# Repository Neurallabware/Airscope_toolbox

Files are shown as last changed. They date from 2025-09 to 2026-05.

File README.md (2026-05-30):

<p align="center">
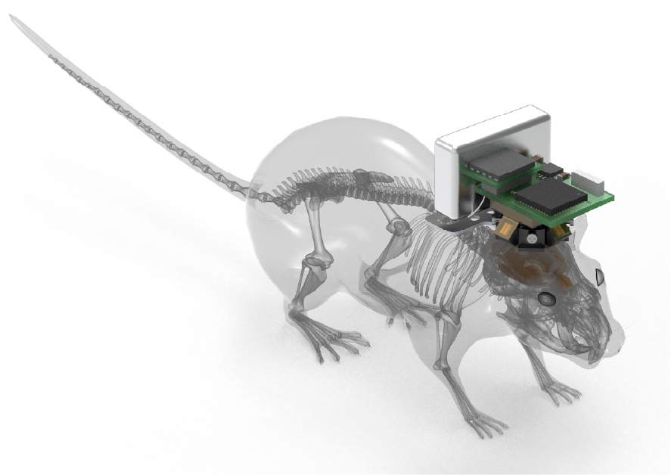
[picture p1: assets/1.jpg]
Airscope
  
</p>

<h1 align="center">Airscope</h1>

<p align="center">
  <b>A 1-gram wireless mesoscope for cortex-wide, single-cell-resolution imaging during unrestricted behaviour</b>
</p>

<p align="center">
  <a href="https://airscope.org/devkit/">Device Docs</a> ·
  <a href="https://airscope-docxs.readthedocs.io/en/latest/">Software Docs</a> ·
  <a href="https://drive.google.com/drive/folders/1z9ibX8Ob2NnCdjQDHI7Z4tdhdspn647B?usp=drive_link">Data Release</a>
</p>

---

Airscope is an open hardware and software platform for wireless mesoscopic calcium imaging in freely behaving mice. The device achieves a **6 mm field of view** at ~4 µm lateral resolution, streams or logs **1600 × 1200 px images at 10 Hz**, and weighs approximately **1 g**.

<p align="center">
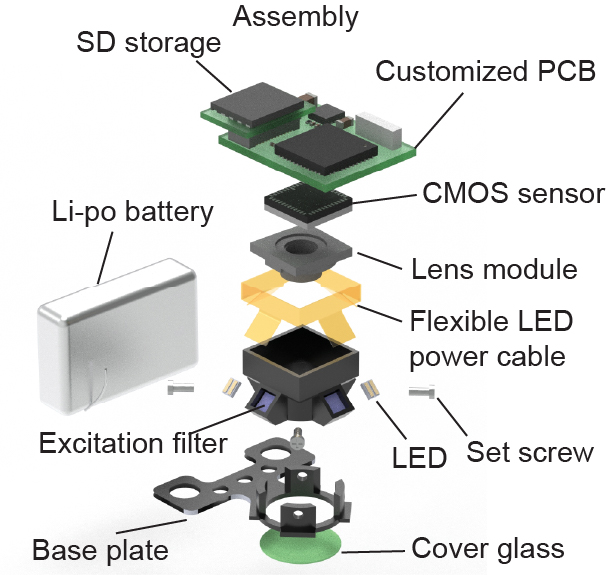
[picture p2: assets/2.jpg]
Airscope examples
  
</p>

This repository accompanies the manuscript:

> **Deciphering cortex-wide neural dynamics of naturally behaving mice by a 1-gram wireless mesoscope**
> *Zhang et al., Nature, 2025* （Manuscript in preparation）

---

## Repository Structure

| Directory | Description |
|---|---|
| [`Structure/`](./Structure) | SolidWorks assemblies and part files — housing, baseplate, optical mount, PCB carrier, flexible LED board |
| [`Zemax/`](./Zemax) | Zemax optical design files for the aspheric module |
| [`Electronics/`](./Electronics) | KiCad projects for the main PCB and auxiliary boards |
| [`Firmware/`](./Firmware) | Embedded code for wireless control, camera acquisition, and device configuration |
| [`DAQ_software/`](./DAQ_software) | Python host software and Windows installer for device discovery, preview, and recording |
| [`Software/`](./Software) | Calcium-imaging processing, behavioural segmentation, and neural-decoding pipelines |
| [`Data_release/`](./Data_release) | Example datasets, visualization notebooks, and download instructions |

---

## Key Capabilities

- **Cortex-wide cellular imaging** — 6 mm FOV with single-cell spatial resolution across the dorsal cortex
- **Untethered operation** — wireless data transfer and on-board logging for freely moving, multi-animal, and aquatic paradigms
- **Integrated acquisition stack** — firmware + host software for discovery, preview, timestamping, and recording
- **Reproducible calcium processing** — motion correction → background removal → neuron segmentation → trace extraction
- **Behavioural analysis** — SAM2Mice for multi-animal tracking; Neuron-BERT for decoding social-interaction outcomes

---

## Software Modules

### Calcium-imaging processing · [`Software/Airscope_ca_processing`](./Software/Airscope_ca_processing)

End-to-end pipeline from raw frames to segmented ROI traces. Accepts image sequences, TIFF stacks, and MP4 input; configured with [Hydra](https://hydra.cc) for reproducible batch runs.

```bash
cd Software/Airscope_ca_processing
conda create -n PICO python=3.10 && conda activate PICO
pip install -r requirements.txt && pip install -e .
```

```bash
airscope-process \
  data_path=/path/to/session/frames \
  out_path=/path/to/session/analysis \
  rmbg.gpu_ids=0 rmbg.multi_gpu=false
```

Primary outputs: `seg_results_filtered.mat`, `infer_results_filtered.mat`, `cm_filtered.mat`

---

### SAM2Mice · [`Software/SAM2Mice`](./Software/SAM2Mice)

SAM 2–based mouse segmentation and tracking. Supports manual prompts, YOLOv11 auto-prompts, and bootstrapped inference for videos that exceed GPU memory.

```bash
cd Software/SAM2Mice
pip install torch==2.6.0 torchvision==0.21.0 torchaudio==2.6.0 --index-url https://download.pytorch.org/whl/cu124
pip install -e ".[notebooks]" && python setup.py build_ext --inplace
```

Notebooks in [`Software/SAM2Mice/notebooks_SAM2-MICE`](./Software/SAM2Mice/notebooks_SAM2-MICE) cover basic segmentation, long-video bootstrapping, automatic tracking, and public-dataset examples.

---

### Neuron-BERT · [`Software/Neuron_BERT`](./Software/Neuron_BERT)

Transformer-based decoder for predicting social-interaction outcomes from dual-animal neural activity recordings.

---

### Host acquisition software · [`DAQ_software/`](./DAQ_software)

Dependency-free Python backend — runs without any additional packages:

```bash
cd DAQ_software/airscope_pybackend
python server.py
# UI available at http://127.0.0.1:8765/
```

A packaged Windows installer is also provided at [`DAQ_software/airscope.msi`](./DAQ_software/airscope.msi).

---

## Data Release

Example datasets are hosted on [Google Drive](https://drive.google.com/drive/folders/1z9ibX8Ob2NnCdjQDHI7Z4tdhdspn647B?usp=drive_link) and documented in [`Data_release/README.md`](./Data_release/README.md).
The Google Drive root README is maintained at [`Data_release/README_google_drive.md`](./Data_release/README_google_drive.md) and can be uploaded to Drive as `README_google_drive.md`.

| Dataset | Contents |
|---|---|
| Enriched habitat | Calcium traces, multi-view behaviour videos, detection boxes, arena annotations, cortical labels, neuron centroids |
| Multi-animal interaction | Calcium traces, SAM2 instance masks, mouse trajectories, cortical labels, neuron centres |
| MCU timestamp | Frame-rate validation files; use `calculate_frame_rate.ipynb` to verify |
| Optical characterisation | USAF 1951 target images and fluorescent grid slides |

Each dataset directory includes a `README.md` and a `visualize_data.ipynb` notebook.

---

## Requirements

| Component | Environment |
|---|---|
| Host acquisition software | Python ≥ 3.9, standard library only |
| Calcium processing | Linux, Python 3.10, CUDA-enabled PyTorch recommended |
| SAM2Mice | Python 3.11, PyTorch 2.6.0, CUDA 12.4 |
| Neuron-BERT | Python 3.x, PyTorch, NumPy, scikit-learn, pandas, matplotlib |

See the component-level `README.md` files for exact commands and configuration.

---

## Licensing

Airscope is distributed as a multi-licence repository:

| Material | Licence |
|---|---|
| Hardware design (`Structure/`, `Electronics/`, `Zemax/`) | CERN-OHL-S-2.0 |
| Software (`DAQ_software/`, `Firmware/`, `Software/`) | GPL-3.0-only |
| Documentation, figures, notebooks, released data | CC-BY-4.0 |

See [`LICENSE`](./LICENSE), [`LICENSES/`](./LICENSES), and [`NOTICE.md`](./NOTICE.md) for the authoritative licence map and third-party notices.

---

## Citation

```bibtex
@article{airscope2025,
  title   = {Deciphering cortex-wide neural dynamics of naturally
             behaving mice by a 1-gram wireless mesoscope},
  author  = {Zhang, Yuanlong and Li, Angran and Yuan, Lekang and
             Wang, Mingrui and Zhao, Weihao and Wang, Zhenbo and
             Zang, Boyang and Zhou, Yangxuan and Yu, Tao and Gao, Lin
             and Wu, Yu and Zhu, Rongkang and Tian, Mengyi and Li, Kun
             and Wu, Jiamin and Dai, Pu and Dai, Qionghai},
  journal = {Nature},
  year    = {2025},
  note    = {Manuscript in preparation}
}
```

## Documentation

- Device assembly, acquisition, and operation: <https://airscope.org/devkit/>
- Processing pipelines, notebooks, and examples: <https://airscope-docxs.readthedocs.io/en/latest/>

## Contact

Questions, bug reports, and suggestions can be submitted via the issue tracker or sent to the corresponding authors listed in the manuscript.

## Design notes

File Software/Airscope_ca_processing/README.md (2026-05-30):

# Airscope calcium imaging processing

Official processing code for Deciphering cortex-wide neural dynamics of naturally behaving mice by 1-gram wireless mesoscope.

<p align="center">
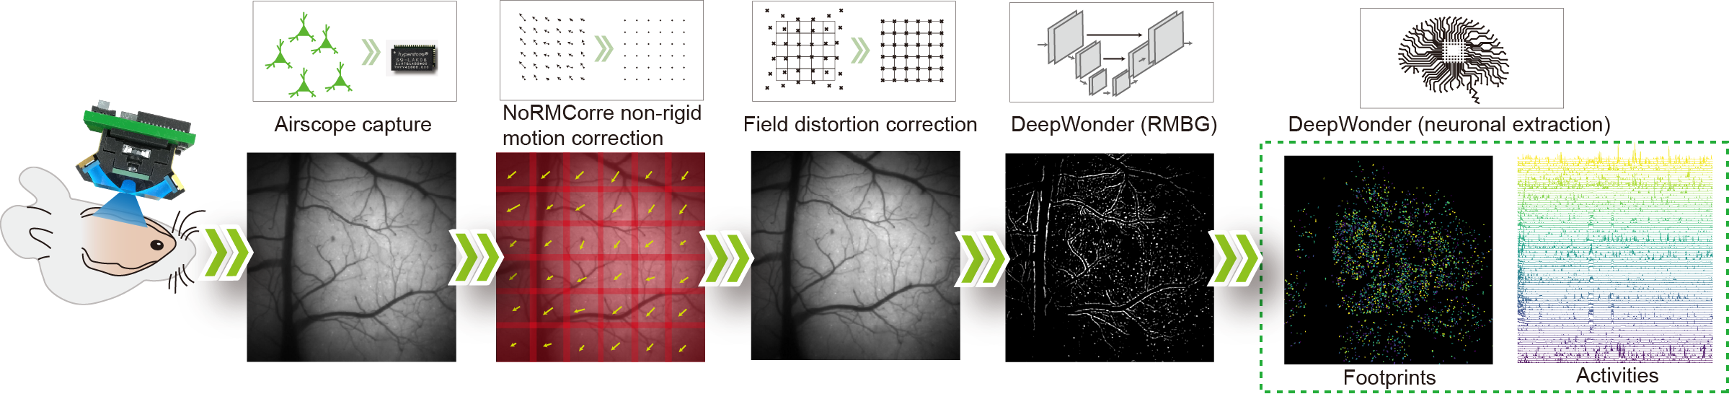
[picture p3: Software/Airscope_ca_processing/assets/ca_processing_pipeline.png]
  
</p>
Airscope_ca_processing processes sequential imaging frames through motion correction,preprocessing, background removal, neuron segmentation, and trace export.

- End-to-end processing pipeline for cortex-wide PICO calcium imaging.
- Suite2p-style or CaImAn-style motion correction configs.
- Learned background removal and vessel-aware filtering.
- Hydra-based configuration for reproducible batch processing.
- Exported masks and traces for downstream analysis.

## Installation

The tested environment is Linux with Python 3.10 and CUDA 11.8.

```bash
conda create -n PICO python=3.10
conda activate PICO
pip install -r requirements.txt
pip install -e .
```

Check the installation:

```bash
python - <<'PY'
import torch
import Airscope_ca
print("Airscope_ca import OK")
print("torch:", torch.__version__, "cuda:", torch.version.cuda)
print("cuda available:", torch.cuda.is_available())
PY
```

## Checkpoints

Download the checkpoint files from:

[[`Google Drive`](https://drive.google.com/drive/folders/1UuLxzTA0PmYvqz8UPbQ9a1BIXx_mHZjt?dmr=1&ec=wgc-drive-%5Bmodule%5D-goto)]

Place the downloaded files under the repository-level `ckpt/` directory:

```text
ckpt/
  CorrectionMap.npz
  background_rejection_ckpt_resize_2
  vessel_model.pt
  yolo_v8s.pt
```

The default configs expect these paths. If you store the files elsewhere, update the corresponding config values under `configs/`.

## Input Format

The pipeline supports `jpg`, `tif`, and `mp4` inputs through `data_format`.
For image sequences, use grayscale frames named by frame index:

```text
data/session/frames/
  frame_0.jpg
  frame_1.jpg
  frame_2.jpg
  ...
```

For TIFF input, use the same naming pattern with `.tif`. For MP4 input, set
`data_path` to the MP4 file path, or to a directory containing exactly one
`.mp4` file. The number of frames is inferred from `data_format` unless
`set_frame_num` is provided.

## Running

Run the full pipeline:

```bash
airscope-process \
  data_path=/path/to/session/frames \
  out_path=/path/to/session/analysis \
  rmbg.gpu_ids=0 \
  rmbg.multi_gpu=false
```

For a short smoke test:

```bash
airscope-process \
  data_path=/path/to/session/frames \
  out_path=/tmp/pico_smoke_test \
  set_frame_num=100 \
  rmbg.gpu_ids=0 \
  rmbg.multi_gpu=false \
  save_debug_video=false
```

Common overrides:

| Override | Description |
| --- | --- |
| `data_path` | Input frame directory for `jpg`/`tif`, or MP4 path for `mp4` |
| `data_format=jpg/tif/mp4` | Select input format |
| `out_path` | Output directory |
| `set_frame_num` | Limit the number of processed frames; `0` infers all frames |
| `motion=caiman` / `motion=suite2p` | Select motion correction config |
| `rmbg.gpu_ids=0,1` | Select GPUs for background removal |
| `rmbg.multi_gpu=true` | Enable multi-GPU background removal |
| `jump_to_rmbg=true` | Reuse existing motion/preprocessing outputs |
| `jump_to_seg=true` | Reuse existing background-removed output |
| `save_debug_video=false` | Disable debug AVI export |

Typical outputs include:

```text
Analysis/
├── log_file.log
├── badframe_replaced.avi                    # optional raw-frame QC video
├── mc/
│   ├── motion_corrected.zarr                # motion-corrected calcium movie
│   ├── suite2p_shifts.png                   # rigid x/y shift diagnostic
│   ├── suite2p_refImg.png                   # registration reference image
│   └── suite2p_refImg.npy                   # numeric reference image
├── preprocess/
│   └── video_preprocessed.zarr              # distortion/intensity corrected movie
├── rmbg/
│   └── rmbg.zarr                            # neuron-enhanced movie after background removal
├── vessel_image.tif                         # vessel-channel image used for exclusion
├── vessel_mask.tif                          # raw vessel mask
├── vessel_mask.png                          # vessel-mask QC figure
├── vessel_mask_clean.tif                    # small-component cleaned vessel mask
├── vessel_mask_dilate.tif                   # dilated vessel mask used for ROI filtering
└── seg_results_thresh_pmap_<value>/
    ├── patch_<row>_<col>/                   # patch-level segmentation workspace
    ├── seg_results.mat                      # unfiltered ROI masks
    ├── infer_results.mat                    # unfiltered calcium traces
    ├── cm.mat                               # unfiltered ROI center coordinates
    ├── SEG_SUM.png                          # unfiltered summed ROI mask
    ├── cm.png / cm.svg                      # unfiltered ROI-center plot
    ├── seg_results_filtered.mat             # vessel/shape filtered ROI masks
    ├── infer_results_filtered.mat           # filtered calcium traces
    ├── cm_filtered.mat                      # filtered ROI center coordinates
    ├── SEG_SUM_filtered.png                 # filtered summed ROI mask
    ├── cm_wo_vessel.png / cm_wo_vessel.svg  # filtered ROI-center plot
    ├── neuron_mask.png / neuron_mask.svg    # filtering summary overlay
    └── Neuron_trace/
        ├── whole_neurons.png
        └── <start>_to_<end>.png             # trace panels by ROI block
```

The final files used for downstream calcium analysis are usually
`seg_results_filtered.mat`, `infer_results_filtered.mat`, and `cm_filtered.mat`.

## Notebooks

Interactive QC notebooks are provided for each processing stage (motion correction, preprocessing, background removal, segmentation, and export). See [`notebooks/README.md`](notebooks/README.md) for demo data download, path setup, and the full stage map.

## Configuration

Configs are stored in `configs/`. The top-level config is:

```text
configs/config.yaml
```

Default groups:

```text
configs/motion/
configs/preprocessing/
configs/rmbg/
configs/segmentation/
```

Hydra overrides can be passed directly on the command line.

## Citation

If this code is useful for your work, please cite:

```text
Yuanlong Zhang, Angran Li, Lekang Yuan, Mingrui Wang.
Deciphering cortex-wide neural dynamics of naturally behaving mice by 1-gram wireless mesoscope.
```

See `CITATION.cff` for machine-readable citation metadata.

## License

This repository is released under the GNU General Public License v3.0 only. See `LICENSE`.

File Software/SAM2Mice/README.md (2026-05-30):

# SAM2Mice: Zero-Shot Multi-Animal Semantic Segmentation

[[`SAM 2 Paper`](https://arxiv.org/abs/2408.00714)] [[`YOLO v11 Paper`](https://www.arxiv.org/abs/2410.17725)] [[`BibTeX`](#citation)]

**SAM2Mice** extends the SAM 2 video segmentation framework for multi-animal mouse segmentation and tracking. It combines SAM2Mice checkpoints, YOLOv11 prompt generation, manual SAM2 prompt workflows, and bootstrapped long-video inference.

Highlights:

- Curated multi-mouse segmentation data with diverse camera views and environments.
- Bootstrapping inference for long videos that cannot be loaded into GPU memory at once.
- Benchmarking support against DeepLabCut and SuperAnimal using MOT metrics.

<p align="center">
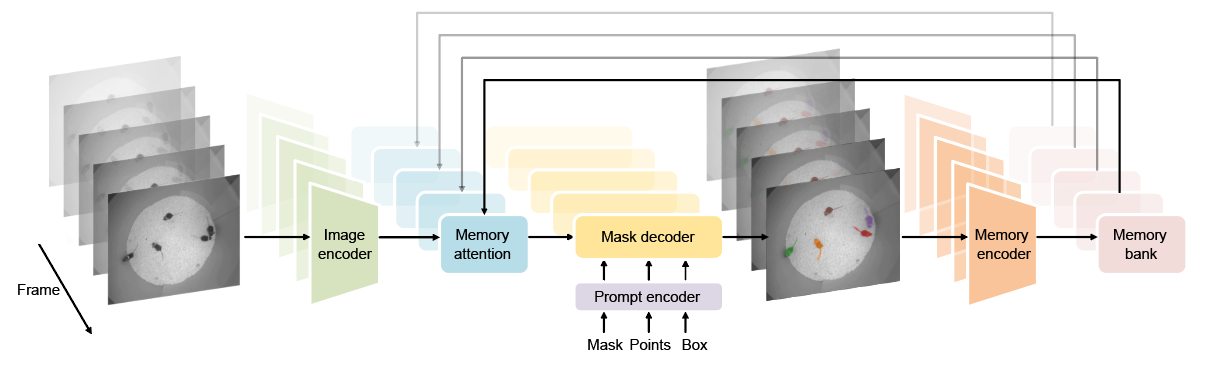
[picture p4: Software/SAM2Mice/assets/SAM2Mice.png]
SAM2Mice
  
</p>

<p align="center">
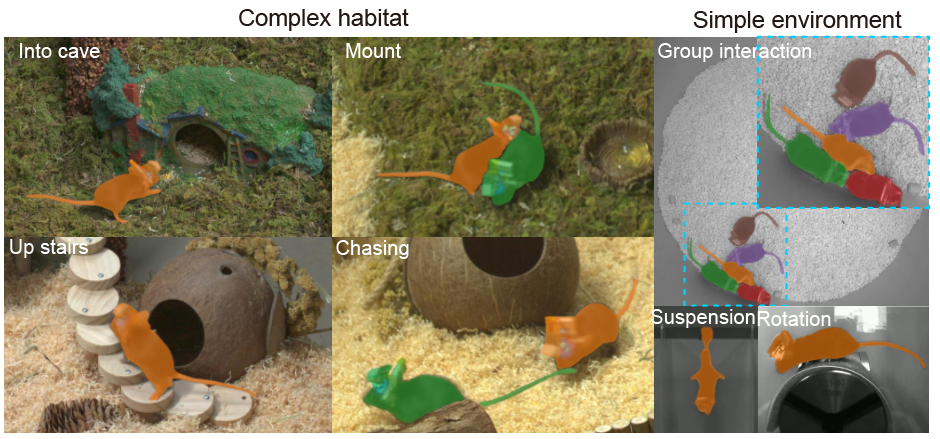
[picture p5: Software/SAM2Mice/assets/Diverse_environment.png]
Diverse environments
  
</p>

## Quick Start

Create or activate a Python environment first. We use `python=3.11`, `torch>=2.6.0`, `torchvision>=0.21.0`, and CUDA 12.4 in our demo environment.

```bash
pip install torch==2.6.0 torchvision==0.21.0 torchaudio==2.6.0 --index-url https://download.pytorch.org/whl/cu124
pip install -e ".[notebooks]"
python setup.py build_ext --inplace
```

Download the SAM2Mice checkpoint:

```bash
cd checkpoints
bash download_ckpts.sh
cd ..
```

Download the YOLOv11 detector checkpoint:

```bash
cd checkpoints_detection
bash download_ckpts.sh
cd ..
```

The YOLO checkpoint is intended for top-down open-field videos. You can also download the SAM2Mice checkpoint directly from [Google Drive](https://drive.google.com/file/d/1aTYiL1qt23vUAGbHvh2Yrk3r16i95bnU/view?usp=drive_link).

## Notebooks

Run the notebooks in order if you are new to the project:

| Order | Notebook | Purpose |
| --- | --- | --- |
| 1 | [`01_basic_video_segmentation.ipynb`](./notebooks_SAM2-MICE/01_basic_video_segmentation.ipynb) | Manual prompts and YOLO-generated prompts on one video. |
| 2 | [`02_bootstrapping_long_video.ipynb`](./notebooks_SAM2-MICE/02_bootstrapping_long_video.ipynb) | Long-video segmentation with bootstrapped frame batches. |
| 3 | [`03_auto_tracking_dynamic_ids.ipynb`](./notebooks_SAM2-MICE/03_auto_tracking_dynamic_ids.ipynb) | Automatic tracking with dynamic IDs. |
| 4 | [`04_public_datasets_demo.ipynb`](./notebooks_SAM2-MICE/04_public_datasets_demo.ipynb) | Public mouse behavior dataset examples. |
| 5 | [`05_vos_inference_advanced.ipynb`](./notebooks_SAM2-MICE/05_vos_inference_advanced.ipynb) | Advanced VOS inference utilities. |

Demo data can be downloaded from [Google Drive](https://drive.google.com/drive/folders/1h3JZ6n-LhZRwAsLCKLH60XWioy7f3WPZ). See [`docs/google_drive_data.md`](./docs/google_drive_data.md) for the full folder structure and per-file Drive IDs.

## Manual Prompts

Manual SAM2 prompts are saved as LabelMe-compatible `.json` files next to extracted frames. SAM2Mice supports two prompt creation tools:

- **LabelMe desktop GUI**: use this when you have a local graphical desktop or X11 forwarding.
- **SAM2-Mice browser prompt tool**: use `launch_annotator` on a remote server or headless workstation.

See the standalone manual prompt guide: [`docs/prompts/README.md`](./docs/prompts/README.md).

## Inference Workflows

SAM2Mice supports two prompt sources:

- `manual`: read LabelMe-style `.json` prompt files from the frame directory.
- `detection`: use YOLOv11 to generate prompts automatically.

When using `prompt_source="detection"`, the supported `prompt_type` values are `box`, `point`, and `mask`.

Results are automatically saved as a gzip-compressed pickle (`segment_masks.pickle`) in `save_dir`. See [`docs/results_pkl.md`](./docs/results_pkl.md) for save/load and re-rendering details.

### Basic Video Segmentation

<details>
<summary><b>Manual prompts (point)</b></summary>

Extract frames and launch the browser-based GUI annotator to place point prompts on the first frame, then run segmentation:

```python
from SAM2_Mice.segmentation import VideoSegmentationInference
from SAM2_Mice.utils import launch_annotator

model_cfg = "configs/sam2.1/sam2.1_hiera_b+.yaml"
checkpoint_path = "checkpoints/SAM2_Mice_base_plus.pt"
video_path = "data/test_video.mp4"
frames_dir = "data/frames"

predictor = VideoSegmentationInference(
    model_cfg=model_cfg,
    checkpoint_path=checkpoint_path,
)

predictor.extract_frames_before_seg(
    video_path=video_path,
    frame_dir=frames_dir,
)

# Launch GUI to annotate the first frame; saves a LabelMe-compatible .json prompt file
launch_annotator(frames_dir=frames_dir)

predictor.run(
    video_path=None,
    frames_dir=frames_dir,
    prompt_source="manual",
    prompt_type="point",
    save_dir="results/base",
    fps=20,
)
```

</details>

### Bootstrapping Long Videos

Processing high-resolution long videos with the standard SAM 2 video predictor can be GPU-intensive because all frames are loaded into memory. SAM2Mice bootstrapping splits the video into overlapping frame batches and carries prompts forward through the shared boundary frame.

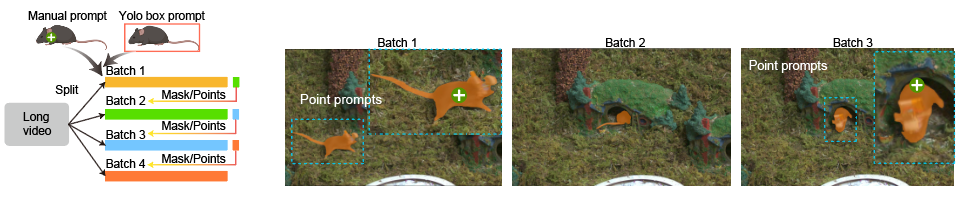
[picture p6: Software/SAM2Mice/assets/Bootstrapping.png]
Bootstrapping


<details>
<summary><b>Manual prompts (point)</b></summary>

Extract batched frames, annotate the first frame with the GUI, then run bootstrapped segmentation:

```python
from SAM2_Mice.segmentation import BootstrappingVideoSegmentationInference
from SAM2_Mice.utils import launch_annotator

model_cfg = "configs/sam2.1/sam2.1_hiera_b+.yaml"
checkpoint_path = "checkpoints/SAM2_Mice_base_plus.pt"
video_path = "data/test_video.mp4"
frames_dir = "data/bootstrap_frames"
batch_size = 300

predictor = BootstrappingVideoSegmentationInference(
    model_cfg=model_cfg,
    checkpoint_path=checkpoint_path,
)

predictor.extract_bootstrapping_frames(
    video_path=video_path,
    batch_size=batch_size,
    batch_save_dir=frames_dir,
)

# Launch GUI to annotate the first frame of the first batch
launch_annotator(frames_dir=frames_dir)

predictor.run_bootstrapping(
    video_path=None,
    frames_dir=frames_dir,
    frame_interval=batch_size,
    extract_frame=False,
    prompt_source="manual",
    prompt_type="point",
    detection_frame_idx=0,
    detection_ckpt_path="checkpoints_detection/yolo11l_openfield_five_mice.pt",
    save_dir="results/bootstrapping",
    fps=20,
)
```

</details>

### YOLO Prompt Generation

YOLOv11 can generate the first-frame prompts automatically:

- `box`: use detector boxes directly.
- `point`: sample points from SAM2 masks predicted from detector boxes.
- `mask`: use SAM2 masks predicted from detector boxes.

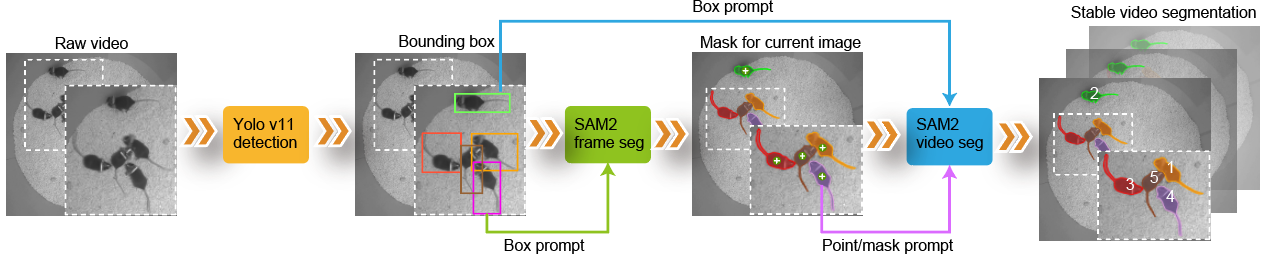
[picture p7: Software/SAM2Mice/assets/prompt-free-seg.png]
Prompt-free segmentation


> **Note:** The YOLO detector is trained on SAM2Mice masks from a specific recording setup (top-down open-field view). It works best when the new video matches that setup closely. For new environments or camera angles, re-train a YOLO detector on SAM2-generated masks from a short representative clip of the new recording — see [`training/README.md`](./training/README.md).

Set `prompt_source="detection"` in either the basic or bootstrapping workflow to use this mode.

<details>
<summary><b>YOLO automatic prompts (point)</b></summary>

Use YOLOv11 to generate point prompts automatically from the first frame — no manual annotation needed:

```python
from SAM2_Mice.segmentation import VideoSegmentationInference

model_cfg = "configs/sam2.1/sam2.1_hiera_b+.yaml"
checkpoint_path = "checkpoints/SAM2_Mice_base_plus.pt"
video_path = "data/test_video.mp4"
frames_dir = "data/frames"

predictor = VideoSegmentationInference(
    model_cfg=model_cfg,
    checkpoint_path=checkpoint_path,
)

predictor.extract_frames_before_seg(
    video_path=video_path,
    frame_dir=frames_dir,
)

predictor.run(
    video_path=None,
    frames_dir=frames_dir,
    prompt_source="detection",
    prompt_type="point",
    detection_ckpt_path="checkpoints_detection/yolo11l_openfield_five_mice.pt",
    save_dir="results/base",
    fps=20,
)
```

</details>

### Auto-Tracking with Dynamic IDs

This mode integrates YOLOv11 detection with SAM2Mice segmentation for prompt-free multi-animal tracking and dynamic ID assignment. It is still under development and may be less stable than the standard workflows.

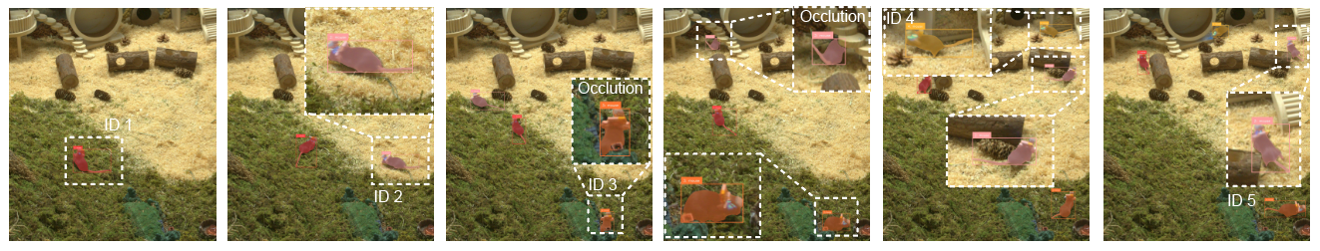
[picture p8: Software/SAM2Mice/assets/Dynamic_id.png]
Dynamic IDs


<details>
<summary><b>Code</b></summary>

```python
from SAM2_Mice.segmentation import auto_tracking_with_sam2

auto_tracking_with_sam2(
    video_path="data/test_video.mp4",
    frames_dir="data/frames",
    output_dir="results/tracking",
    sam2_checkpoint="checkpoints/SAM2_Mice_base_plus.pt",
    model_cfg="configs/sam2.1/sam2.1_hiera_b+.yaml",
    detection_ckpt_path="checkpoints_detection/yolo11l_openfield_five_mice.pt",
    prompt_type="mask",
    frame_step=1,
    frame_rate=20,
    detection_conf=0.5,
    iou_threshold=0.3,
    extract_frames=True,
    object_label="mouse",
)
```

</details>

## Training

Training data preparation, SAM2Mice fine-tuning, and YOLOv11 detector training are documented in [`training/README.md`](./training/README.md).

## Benchmark

Tracking metric evaluation and comparisons with DeepLabCut and SuperAnimal are documented in [`SAM2_Mice/benchmark/README.md`](./SAM2_Mice/benchmark/README.md).

## Citation

If you find this project helpful for your research, please consider citing the following BibTeX entry.

```BibTex
@misc{ravi2024sam2segmentimages,
      title={SAM 2: Segment Anything in Images and Videos},
      author={Nikhila Ravi and Valentin Gabeur and Yuan-Ting Hu and Ronghang Hu and Chaitanya Ryali and Tengyu Ma and Haitham Khedr and Roman Rädle and Chloe Rolland and Laura Gustafson and Eric Mintun and Junting Pan and Kalyan Vasudev Alwala and Nicolas Carion and Chao-Yuan Wu and Ross Girshick and Piotr Dollár and Christoph Feichtenhofer},
      year={2024},
      eprint={2408.00714},
      archivePrefix={arXiv},
      primaryClass={cs.CV},
      url={https://arxiv.org/abs/2408.00714},
}
```

## License

The Airscope release of SAM2Mice software is distributed under the GNU General
Public License v3.0 only. See [`LICENSE`](./LICENSE). Third-party components,
assets, and datasets retain their own license terms where noted.

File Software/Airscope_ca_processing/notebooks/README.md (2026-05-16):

## Demo Data

Download the demo dataset (JPEG frame sequence) from Google Drive:

**[Download demo data (frames.zip)](https://drive.google.com/file/d/1P-wrqrqEMpr30H5Tcj7h8rFYt6ORBHGP/view?usp=drive_link)**

After downloading, extract the archive to a directory of your choice:

```bash
unzip frames.zip -d /your/data/directory/
# The extracted folder should be named "frames"
# e.g. /your/data/directory/frames/
```

Then update the `DATA_PATH` variable at the top of **each notebook** to point to the extracted `frames` folder:

```python
DATA_PATH = "/your/data/directory/frames"
```

> `OUT_PATH` is derived automatically as a sibling `Analysis/` folder and does not need to be changed.

## Stage Map

The notebooks are organized as independent, resumable stage reports:

| Notebook | Stage | Principal QC |
|---|---|---|
| 01 | raw loading + motion correction | raw/corrected frame montages, projections, before/after frames, Suite2p diagnostics |
| 02 | preprocessing | corrected vs preprocessed movie, vessel mask overlay, preprocessing output inventory |
| 03 | background removal | neuron-enhanced frames, residual maps, projection statistics |
| 04 | neural signal extraction | ROI center map, ROI area distribution, summed ROI mask |
| 05 | final export | filtered masks, vessel-exclusion result, ROI-boundary overlay |

## Final Output Structure

All notebooks use:

```python
OUT_PATH = DATA_PATH.replace("frames", "Analysis")
```

After a complete run, the analysis directory is expected to contain the following
stage outputs. Optional debug videos are only written when `save_debug_video`
is enabled in the composed Hydra config.

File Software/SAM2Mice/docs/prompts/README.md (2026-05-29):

# SAM2-Mice Manual Prompt Guide

SAM2Mice manual prompts are SAM2 input prompts, not training annotations. They are stored as LabelMe-compatible `.json` files next to extracted video frames. The segmentation code reads these JSON files when `prompt_source="manual"`.

You can create the JSON files with either:

- LabelMe desktop GUI
- SAM2-Mice browser prompt tool, exposed by `launch_annotator`

Both tools write one prompt JSON file per prompted frame, for example:

```text
frames/
├── 00000.jpg
├── 00000.json
├── 00001.jpg
├── 00002.jpg
└── ...
```

For bootstrapping inference, add prompts to the relevant batch folder, usually `batch_1`:

```text
bootstrap_frames/
├── batch_1/
│   ├── 00000.jpg
│   ├── 00000.json
│   └── ...
├── batch_2/
└── ...
```

## Option A: LabelMe Desktop GUI

Use LabelMe when you have a local desktop environment or X11 forwarding.

```bash
labelme /path/to/frames
```

For bootstrapping:

```bash
labelme /path/to/bootstrap_frames/batch_1
```

In LabelMe:

1. Open a frame.
2. Choose polygon mode and draw one polygon prompt around each mouse.
3. Set `label` to `mouse`.
4. Set `group_id` to the mouse ID. Use different `group_id` values for different mice, and keep the same `group_id` for the same mouse across prompted frames.
5. Save the prompt JSON. LabelMe writes `<frame_stem>.json` next to the image.

See the LabelMe usage example video: [`assets/labelme_usage_example.mp4`](../../assets/labelme_usage_example.mp4).

Example polygon prompt:

```json
{
  "shapes": [
    {
      "label": "mouse",
      "points": [
        [424.51, 1120.64],
        [311.61, 1212.58],
        [208.38, 1254.51],
        [239.03, 1204.51]
      ],
      "group_id": 1,
      "shape_type": "polygon",
      "flags": {}
    }
  ]
}
```

## Option B: SAM2-Mice Browser Prompt Tool

Use `launch_annotator` when running on a remote server or headless workstation. It starts a Gradio browser UI and saves LabelMe-compatible JSON files.

```python
from SAM2_Mice.utils import launch_annotator

launch_annotator(frames_dir="/path/to/frames", port=7860)
```

For bootstrapping:

```python
from SAM2_Mice.utils import launch_annotator

launch_annotator(frames_dir="/path/to/bootstrap_frames/batch_1", port=7860)
```

If the server is remote, forward the port from your local machine:

```bash
ssh -L 7860:localhost:7860 user@server
```

Then open:

```text
http://localhost:7860
```

The browser prompt tool can resume from existing JSON files in the same frame directory.

## Use Saved Manual Prompts

After saving prompt JSON files, run SAM2Mice with `prompt_source="manual"`.

Basic video predictor:

```python
predictor.run(
    video_path=None,
    frames_dir="/path/to/frames",
    prompt_source="manual",
    prompt_type="box",
    save_dir="results/manual",
    fps=20,
)
```

Bootstrapping predictor:

```python
predictor.run_bootstrapping(
    video_path=None,
    frames_dir="/path/to/bootstrap_frames",
    frame_interval=300,
    extract_frame=False,
    prompt_source="manual",
    prompt_type="point",
    save_dir="results/manual_bootstrap",
    fps=20,
)
```

## Choosing a Tool

Use LabelMe if you already have a graphical desktop or prefer the standard LabelMe workflow.

Use `launch_annotator` if you work on a remote GPU server, need browser access through SSH port forwarding, or want to resume and edit SAM2Mice manual prompts from a notebook.

The example notebooks expose this choice with:

```python
ANNOTATION_BACKEND = "launch_annotator"  # "labelme" or "launch_annotator"
```

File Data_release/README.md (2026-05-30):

# Airscope Data Release

This directory contains supplementary datasets and visualization notebooks for
the Airscope release. Each experiment has its own README with the download
link, file descriptions, and minimal loading examples.

Public data release: [Google Drive](https://drive.google.com/drive/folders/1z9ibX8Ob2NnCdjQDHI7Z4tdhdspn647B?usp=drive_link)

Google Drive root README template:
[`README_google_drive.md`](README_google_drive.md). Upload this file to the
Drive root as `README_google_drive.md` when updating the public data folder.

## Experiments

| Dataset | Local directory | Description |
| --- | --- | --- |
| Enriched habitat | [`experiments/enriched_habitat`](experiments/enriched_habitat) | Single-animal Airscope recording in a 5 m2 naturalistic habitat with synchronized multi-view behavior videos, detection boxes, and top-down arena-region annotations. |
| Multi-animal interaction | [`experiments/muiti_animal_interaction`](experiments/muiti_animal_interaction) | Multi-animal Airscope recording with behavior videos, SAM2 instance masks, aligned neural activity, cortical labels, neuron centers, and mouse mask centers. |

## MCU Timestamp

Download: [Google Drive](https://drive.google.com/drive/u/0/folders/1EPN6YSidfCAPXQBSYq9nOefI76L-_FHE)

The `MCU_timestamp/` directory contains MCU (Microcontroller Unit) timestamp files for frame rate validation across neural recording. Use `calculate_frame_rate.ipynb` to verify the actual frame rate from the recorded timestamps.

## Optical characteristic data

The `optical_characteristic/` directory contains USAF 1951 target images, and fluorescent grid slide images.

## Directory Layout

```text
Data_release/
├── optical_characteristic/
├── MCU_timestamp/
└── experiments/
    ├── enriched_habitat/
    │   ├── README.md
    │   └── visualize_data.ipynb
    └── muiti_animal_interaction/
        ├── README.md
        ├── visualize_data.ipynb
        └── outputs/
```

## Quick Start

1. Open the README for the dataset you want to use.
2. Download the data from the Google Drive link listed in that dataset README.
3. Place the downloaded files in the directory expected by the notebook, or
   update the notebook path configuration cell.
4. Run `visualize_data.ipynb` from top to bottom.

## Dataset Notes

### Enriched habitat

Main release files:

- `data_aligned.mat`: aligned calcium traces, behavior timestamps, cortical
  labels, and neuron centroid coordinates.
- `video/`: synchronized behavior videos from top-down and side-view cameras.
- `detection_box.json`: mouse detection bounding boxes for video frames.
- `CD00362AAK00005_0000.json`: LabelMe top-down arena-region annotation.

See [`experiments/enriched_habitat/README.md`](experiments/enriched_habitat/README.md)
for detailed variable descriptions and loading examples.

### Multi-animal interaction

Main release files:

- `data_aligned.mat`: aligned calcium traces and behavior-derived mouse centers
  for all animals.
- `behavior.mp4`: raw multi-animal behavior video.
- `behavior_with_mask.avi`: behavior video with SAM2 instance masks overlaid.
- `segment_mask.pickle`: packed SAM2 binary masks for each video frame.

See [`experiments/muiti_animal_interaction/README.md`](experiments/muiti_animal_interaction/README.md)
for detailed variable descriptions, mask unpacking, and loading examples.

## License

Unless otherwise noted, released data, dataset documentation, figures, and
visualization notebooks in this directory are distributed under the Creative
Commons Attribution 4.0 International License (CC-BY-4.0). See the top-level
[`LICENSE`](../LICENSE) file for the repository-wide license map.

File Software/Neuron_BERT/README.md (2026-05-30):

# Neuron-BERT predictor

We proposed a deep learning framework for analyzing calcium imaging data from dual-mouse behavioral experiments using two-stream neural architectures.  Neural recordings were tokenized in time, treating each time point as a token. The sequence from each animal, without rank labels, was passed to a dedicated transformer encoder to produce an embedded representation of that animal’s activity.This repository implements multiple model architectures including Uni-stream BERT and Dual-stream-BERT predicting the tubetest outcome (win/lose) from neural calcium signals.

<div align="center">
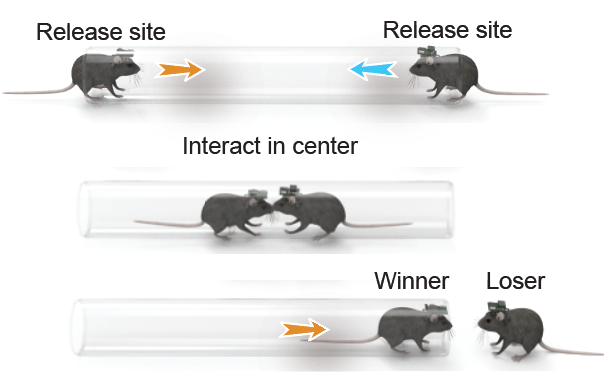
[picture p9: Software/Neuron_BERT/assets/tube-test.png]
tube test
  
</div>

## Model Architectures

Calcium imaging sequences are high‑dimensional and socially contextual. Classical models (SVM / shallow MLP) ignore structured temporal dependencies and inter‑animal coupling. We proposed two architectures as below:

---
### 1. Neuron‑BERT (Single Stream)
<div align="center">
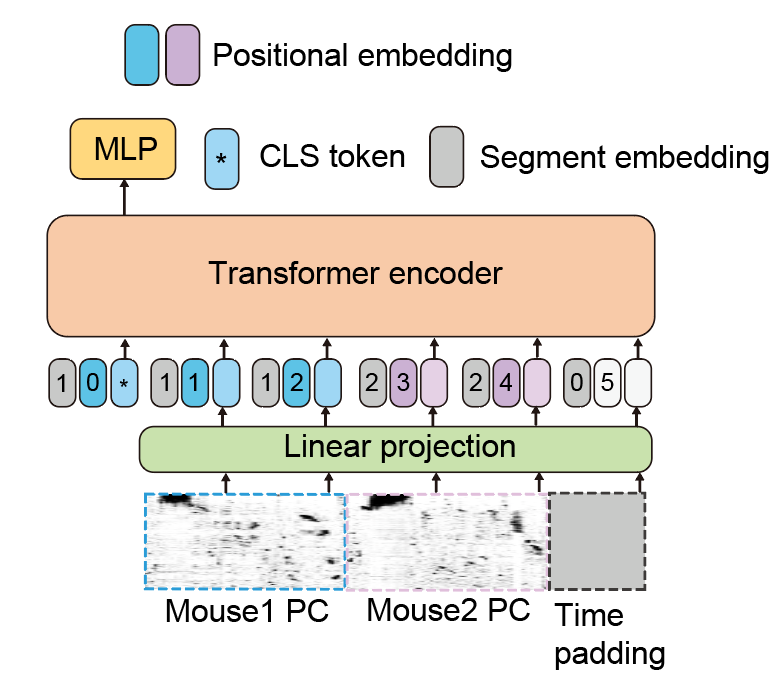
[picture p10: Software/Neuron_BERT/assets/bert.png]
BERT Architecture
  
</div>
Adapts a BERT encoder to neural calcium sequences with:
- Learned positional embeddings
- Bert-liks segment embeddings to separete the two mice
- CLS token–style representation aggregation (classification head on first token)

### 2. Dual‑Stream BERT
<div align="center">
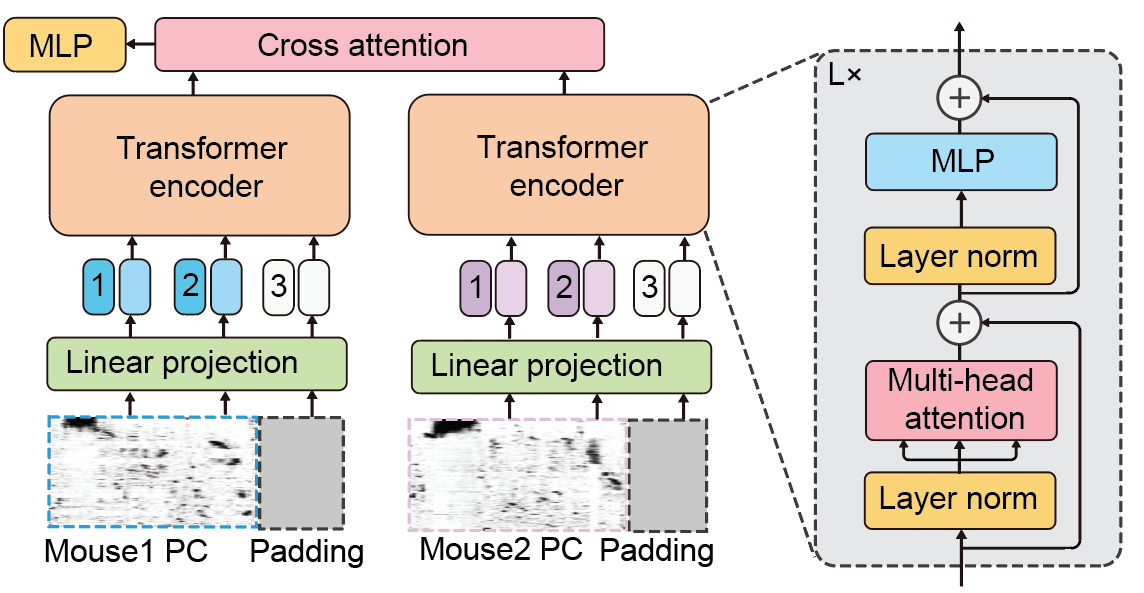
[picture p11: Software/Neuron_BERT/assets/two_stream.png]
Two-Stream Architecture
  
</div>
Two independent temporal Transformer encoders (one per mouse) followed by a fusion head.

---

## Data Format

Each experiment file (e.g. `data_aligned.pkl`) is a pickled Python dict:

```python
{
  'trial_folder_name (mouseA_mouseB)': {
      'start_frame': int, 
      'end_frame': int,  # start and end frame of current trial 
      'neuron_center_{mouse_id}': np.ndarray,          # (num_neurons, 2) or similar
      'neuron_name_{mouse_id}': np.ndarray | list,     # cortical id of each neurons
      'calcium_whole_{mouse_id}': np.ndarray,          # (num_neurons, total_time)
      'trial_{k}': {
          'winner': str,                               # e.g. 'mouseA'
          'time_start_end': np.ndarray,                # [t_start, t_end]
          'calcium_{mouse_id}': np.ndarray             # (num_neurons, trial_time)
      }
  },
  ...
}

```

### Preprocessing
- Trials are already **aligned** across the two animals.
- PCA dimensionality reduction happens inside dataset classes to the fixed dimension `--input_dim`. To reduce processing time, the processed files are saved in the cache dir (see `cache/`) to be loaded.
- Variable length trials are cropped / padded to a fixed `--seq_length` with a corresponding mask.

The dataset class in [dataset.py](datasets\dataset.py) accept a `list[dict]` of the pkl file as input.
For the overview of the dataset, please refer to this [notebook](datasets/data_set_vis.ipynb).

---

## Installation

Minimal setup (adjust torch version for CUDA):

```bash
pip install torch torchvision torchaudio --index-url https://download.pytorch.org/whl/cu121  # or cpu
pip install scikit-learn numpy matplotlib seaborn pandas tqdm jupyter
```

---

## Quick Start (Defaults)

Single‑stream:
```bash
python train_BERT.py --data_dir <dir_to_pickled_data>
```

Dual‑stream:

```bash
python train_dual_stream_BERT.py --data_dir <dir_to_pickled_data>  --depth 4 --embed_dim 256
```

Example log file of Dual-stream BERT can be seen at [log.txt](runs\two_stream_transformer_tube_test\trial_level_emb256_d4_mlp4_drop30_lr0.001_20251112-154352\log.txt). You can view the validation [here](validate_dual_stream.ipynb).

---

### Key CLI Arguments

| Category | Argument | Purpose | Common Values |
|---|---|---|---|
| Data | `--data_dir` | Folder of `.pkl` dictionaries | (required) |
| Splitting | `--split_strategy` | How to partition trials | `trial_level`, `mouse_level`, `file_level` |
| Sequence | `--seq_length` | Crop/pad length (time tokens) | 196 / 392 |
| Dimensionality | `--input_dim` | PCA dimension | 128 / 256 |
| Architecture | `--depth` | Transformer layers | 2–6 |
| Architecture | `--num_heads` | Attention heads | 4 / 8 |
| Fusion (dual) | `--fusion_strategy` | Feature integration | `concat`, `add`, `cross_attention` |
| Training | `--batch_size` | Batch size | 16 / 32 |
| Training | `--lr` | Learning rate | 1e-3 (dual), 1e-4 (single) |
| Training | `--epochs` | Epoch count | 20+ (dual), 100 (single) |
| Regularization | `--drop_ratio` | Dropout | 0.1–0.3 |
| Augmentation | see below | Robustness to noise | tuned per dataset |

Run `python train_dual_stream_BERT.py -h` or `python train_BERT.py -h` for the full list.

---

### Data Augmentation Toolkit

Implemented inside dataset classes (`dataset_augment.py`). You can toggle intensity via probabilities:

| Augmentation | Args | Effect |
|---|---|---|
| Random crop | `--no_random_crop` (flag disables) | Focuses model on sub‑segments; combats overfitting on edge padding |
| Channel shuffle | `--channel_shuffle_prob`, `--channel_shuffle_ratio` | Reorders subset of neuron channels (simulates ROI ordering ambiguity) |
| Channel dropout | `--channel_dropout_prob`, `--channel_dropout_ratio` | Zeros subset of channels (missing neuron simulation) |
| Time masking | `--time_mask_prob`, `--time_mask_ratio` | Random temporal spans masked (encourages temporal redundancy reasoning) |

All augmentations automatically disabled for validation and test splits.

---

## Results (Five‑Fold Cross Validation)

Performance across nine animal pairs (19 held‑out trials per fold):

| Model | Accuracy | Precision | Recall | F1 |
|---|---|---|---|----|
| SVM | 53.45 ± 5.38 | 41.39 ± 24.90 | 76.00 ± 43.36 | 53.48 ± 31.50 |
| MLP | 67.24 ± 8.16 | 94.64 ± 7.36 | 40.44 ± 22.99 | 52.84 ± 20.21 |
| Neuron_BERT (shared) | 66.25 ± 8.39 | 62.62 ± 12.78 | 75.28 ± 25.85 | 66.98 ± 17.40 |
| Two_stream_BERT | **81.82 ± 6.92** | **83.39 ± 3.88** | **81.11 ± 14.93** | **81.62 ± 9.08** |

---

## Citation

If this repository aids your research, please cite:

```bibtex
@software{two_stream_predictor,
  title        = {Two-Stream Calcium Imaging Predictor},
  author       = {Neurallabware},
  year         = {2025},
  url          = {https://github.com/Neurallabware/two_stream_predictor}
}
```

---

## License
GNU General Public License v3.0 only (see `LICENSE`).

---

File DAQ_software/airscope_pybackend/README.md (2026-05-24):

# Airscope host (clean Python edition)

A minimal local daq software that pairs with the Airscope firmware. Two files:

| File | Role |
|---|---|
| `server.py`  | Backend. HTTP server on `127.0.0.1:8765` + UDP responder on `:12345`. |
| `index.html` | Frontend. Single-page UI served by `server.py`. |

A third file, `scopes_registry.json`, is created on first run to remember
discovered scopes across restarts.

## Requirements

- Python 3.9+ (standard library only — no `pip install` needed)
- Windows / macOS / Linux. Local LAN scan uses `arp -a`, present on all three.
- A modern Chromium-based browser (Chrome / Edge / Opera) if you want the
  embedded Serial Monitor — it uses Web Serial.

## Running

```sh
python server.py
```

That's it. The script:

1. Starts the HTTP server on `http://127.0.0.1:8765/`.
2. Starts a UDP listener on `0.0.0.0:12345` that answers `TIME` packets
   with a timestamp string the firmware uses to name its SD folder.
3. Opens your default browser at the local URL.

Flags:

- `--no-browser` — don't auto-open the browser.
- `--port N` — serve HTTP on a different port (UDP port is fixed).

Stop with `Ctrl-C`.

## Frontend (index.html)

The page is what you actually interact with. Refer to wiki for usage instructions.

## Backend (server.py)

Endpoints the frontend calls (all `GET`):

| Path | Purpose |
|---|---|
| `/discover` | Cached registry + last-known live state |
| `/rescan` | Re-issue `/whoami` against every registered scope |
| `/scan` | Probe ARP-table neighbors for `/whoami` |
| `/add-ip?ip=`  | Probe one IP, register on success |
| `/remove?mac=` | Drop a scope from the registry |
| `/save?title=` | Open a folder picker (Tk), return the chosen path |
| `/<filename>`  | Serve any file from this directory (default `index.html`) |

UDP: a single thread binds `0.0.0.0:12345` and replies to `TIME` packets
with `/DD-Mon-YY/HH-MM-SS-mmm`. Scopes use this to pick their SD folder
name when recording starts.

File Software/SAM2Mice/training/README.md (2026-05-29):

# Training Code for SAM 2

This folder contains the training code for SAM 2, a foundation model for promptable visual segmentation in images and videos. 
The code allows users to train and fine-tune SAM 2 on their own datasets (image, video, or both).

## Structure

The training code is organized into the following subfolders:

* `dataset`: This folder contains image and video dataset and dataloader classes as well as their transforms.
* `model`: This folder contains the main model class (`SAM2Train`) for training/fine-tuning. `SAM2Train` inherits from `SAM2Base` model and provides functions to enable training or fine-tuning SAM 2. It also accepts all training-time parameters used for simulating user prompts (e.g. iterative point sampling).
* `utils`: This folder contains training utils such as loggers and distributed training utils.
* `scripts`: This folder contains the script to extract the frames of SA-V dataset to be used in training.
* `loss_fns.py`: This file has the main loss class (`MultiStepMultiMasksAndIous`) used for training.
* `optimizer.py`:  This file contains all optimizer utils that support arbitrary schedulers.
* `trainer.py`: This file contains the `Trainer` class that accepts all the `Hydra` configurable modules (model, optimizer, datasets, etc..) and implements the main train/eval loop.
* `train.py`: This script is used to launch training jobs. It supports single and multi-node jobs. For usage, please check the [Getting Started](README.md#getting-started) section or run `python training/train.py -h`

## Getting Started

The dataset used in SAM2Mice is currently not publicly available. It will be open-sourced after the paper is accepted and published.

We provide fine-tuning configs for the SAM 2.1 models on the Airscope (SAM2Mice) dataset. The available configs are:

| Config | Model | Checkpoint |
|---|---|---|
| `configs/sam2.1_training/sam2.1_hiera_b+_Airscope_finetune.yaml` | Hiera Base+ | `checkpoints/sam2.1_hiera_base_plus.pt` |
| `configs/sam2.1_training/sam2.1_hiera_s_Airscope_finetune.yaml` | Hiera Small | `checkpoints/sam2.1_hiera_small.pt` |
| `configs/sam2.1_training/sam2.1_hiera_l_Airscope_finetune.yaml` | Hiera Large | `checkpoints/sam2.1_hiera_large.pt` |

#### Requirements:
- We assume training on A100 GPUs with **80 GB** of memory.
- Download the SAM2Mice training dataset and set the correct paths in the config file.

#### Steps to fine-tune on Airscope (SAM2Mice) dataset:
- Install the packages required for training by running `pip install -e ".[dev]"`.
- Set the paths for the dataset in `configs/sam2.1_training/sam2.1_hiera_b+_Airscope_finetune.yaml` (or the `_s_` / `_l_` variants):
    ```yaml
    dataset:
        img_folder: /path/to/SAM2Mice_training_dataset/JPEGImages
        gt_folder: /path/to/SAM2Mice_training_dataset/Annotations
        file_list_txt: /path/to/SAM2Mice_training_dataset/train_list.txt
    ```
- To fine-tune using all available GPUs, run:

    ```bash
    python training/train.py \
        -c configs/sam2.1_training/sam2.1_hiera_b+_Airscope_finetune.yaml \
        --use-cluster 0 \
        --num-gpus 8
    ```

- To specify which GPUs to use, set `CUDA_VISIBLE_DEVICES` before the command:

    ```bash
    # Use GPUs 0 and 1 only
    CUDA_VISIBLE_DEVICES=0,1 python training/train.py \
        -c configs/sam2.1_training/sam2.1_hiera_b+_Airscope_finetune.yaml \
        --use-cluster 0 \
        --num-gpus 2

    # Use a single GPU (GPU 2)
    CUDA_VISIBLE_DEVICES=2 python training/train.py \
        -c configs/sam2.1_training/sam2.1_hiera_b+_Airscope_finetune.yaml \
        --use-cluster 0 \
        --num-gpus 1

    # Use GPUs 4, 5, 6, 7
    CUDA_VISIBLE_DEVICES=4,5,6,7 python training/train.py \
        -c configs/sam2.1_training/sam2.1_hiera_b+_Airscope_finetune.yaml \
        --use-cluster 0 \
        --num-gpus 4
    ```

    Note: `--num-gpus` must match the number of GPUs listed in `CUDA_VISIBLE_DEVICES`.

    We also support multi-node training on a cluster using [SLURM](https://slurm.schedmd.com/documentation.html), for example, training on 2 nodes:

    ```bash
    python training/train.py \
        -c configs/sam2.1_training/sam2.1_hiera_b+_Airscope_finetune.yaml \
        --use-cluster 1 \
        --num-gpus 8 \
        --num-nodes 2 \
        --partition $PARTITION \
        --qos $QOS \
        --account $ACCOUNT
    ```
    where partition, qos, and account are optional and depend on your SLURM configuration.

    By default, checkpoints and logs are saved under `sam2_logs/` in the repo root. You can override this in the config:

    ```yaml
    launcher:
      experiment_log_dir: /path/to/your/log/dir  # defaults to ./sam2_logs/${config_name}
    ```

    Training losses can be monitored via `tensorboard` logs stored under `tensorboard/` in the experiment log directory.

    After training/fine-tuning, the new checkpoint (saved in `checkpoints/` in the experiment log directory) can be used as a drop-in replacement for SAM 2.1 released checkpoints.

## SAM2Mice Dataset Preparation

### Data Annotation Pipeline

In the first step, we acquire a dataset encompassing a broad range of experimental conditions, including standard home cages, naturalistic habitats, light conditions, and dark conditions. Next, we apply SAM2 in batch mode to generate semantic masks. We then identify failure cases such as identity loss and label mixing. A human annotator corrects these errors, and an independent reviewer verifies the accuracy, quality, and completeness of the masks. We iterate this pipeline three to five times to improve coverage.

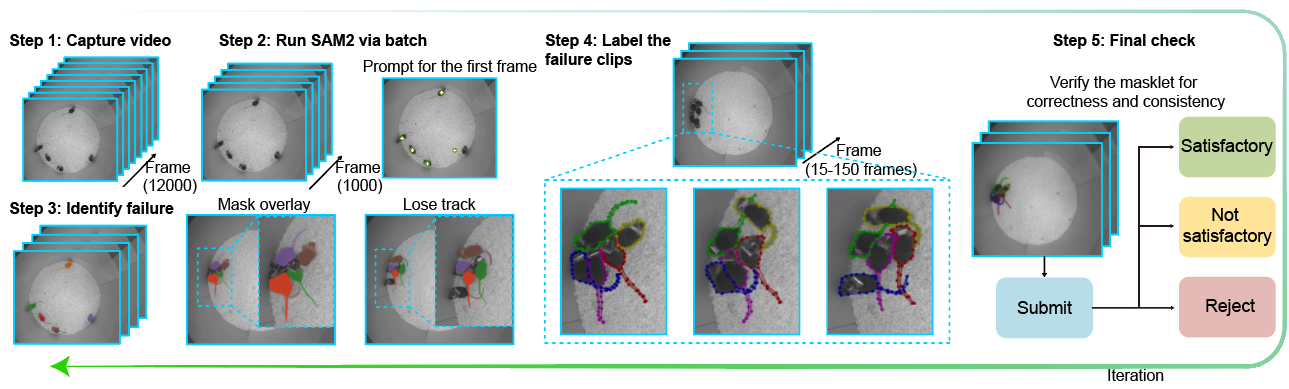
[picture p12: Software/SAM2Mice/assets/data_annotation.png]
Data annotation


### LabelMe Dataset Format

We use [LabelMe](https://github.com/wkentaro/labelme) for mouse mask annotation. Each frame is paired with a corresponding `.json` annotation file:

An example annotated dataset can be downloaded from [Google Drive](https://drive.google.com/file/d/1jCTJk6LRsQnCCKe7qJGZnsDLCochzUym/view?usp=drive_link). The original full SAM2Mice dataset will be open-sourced in the future.

For an advanced VOS inference example, see [`notebooks_SAM2-MICE/05_vos_inference_advanced.ipynb`](../notebooks_SAM2-MICE/05_vos_inference_advanced.ipynb).

<details>
<summary>Raw LabelMe dataset directory</summary>

```text
Root folder
├── <video_name_1>
│   ├── 00000.png
│   ├── 00000.json
│   ├── 00001.png
│   ├── 00001.json
│   └── ...
├── <video_name_2>
│   ├── 00000.png
│   ├── 00000.json
│   ├── 00001.png
│   ├── 00001.json
│   └── ...
└── ...
```

</details>

Convert the raw LabelMe annotations into the [MOSE](https://github.com/henghuiding/MOSE-api) dataset format:

```bash
cd training/dataset_pre
python labelme_to_training_format.py --json_dir <data_dir> --output_dir <output_dir>
```

The converted dataset should contain:

<details>
<summary>Converted MOSE-style dataset directory</summary>

```text
<output_dir>
├── Annotations
│   ├── <video_name_1>
│   │   ├── 00000.png
│   │   ├── 00001.png
│   │   └── ...
│   └── ...
└── JPEGImages
    ├── <video_name_1>
    │   ├── 00000.jpg
    │   ├── 00001.jpg
    │   └── ...
    └── ...
```

</details>

Example dataset:

<p align="center">
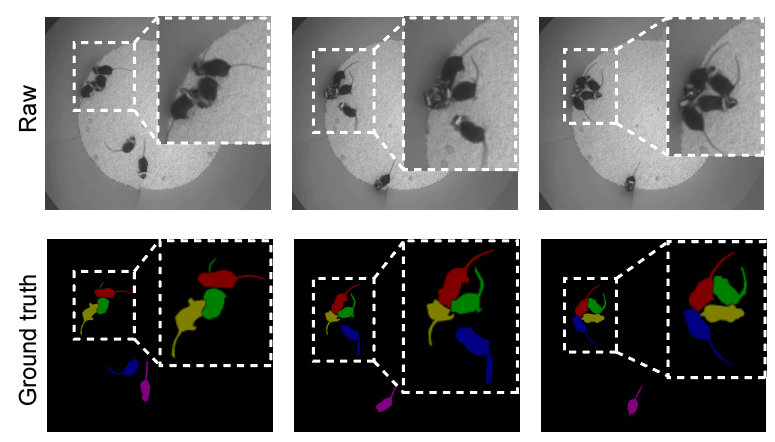
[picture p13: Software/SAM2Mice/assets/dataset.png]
Dataset
  
</p>

## YOLOv11 Detector Training

We convert SAM2Mice masks to bounding boxes to train a YOLO detector for initial prompt generation. The bounding box data for YOLO can be downloaded from [Google Drive](https://drive.google.com/drive/folders/1aLM1k9hvZOTvQtgVzJ2K1oiGWzQ9MZNx?dmr=1&ec=wgc-drive-globalnav-goto).

Convert packed SAM2Mice mask data to YOLO-format training data:

```bash
python SAM2_Mice/detection/train/mask_to_box.py \
    --video /path/to/video.mp4 \
    --pickle /path/to/processed_segments.pkl.gz \
    --images-out ./dataset/images \
    --labels-out ./dataset/labels \
    --mode random \
    --num-frames 200 \
    --class-mode single \
    --seed 42
```

Then edit the dataset paths in [`SAM2_Mice/detection/train/cfg/Airscope_five_mouse.yaml`](../SAM2_Mice/detection/train/cfg/Airscope_five_mouse.yaml) and run:

```bash
python SAM2_Mice/detection/train/train_detection.py
```

## Training on images and videos
The code supports training on images and videos (similar to how SAM 2 is trained). We provide classes for loading SA-1B as a sample image dataset, SA-V as a sample video dataset, as well as any DAVIS-style video dataset (e.g. MOSE). Note that to train on SA-V, you must first extract all videos to JPEG frames using the provided extraction [script](./scripts/sav_frame_extraction_submitit.py). Below is an example of how to setup the datasets in your config to train on a mix of image and video datasets:

```yaml
data:
  train:
    _target_: training.dataset.sam2_datasets.TorchTrainMixedDataset 
    phases_per_epoch: ${phases_per_epoch} # Chunks a single epoch into smaller phases
    batch_sizes: # List of batch sizes corresponding to each dataset
    - ${bs1} # Batch size of dataset 1
    - ${bs2} # Batch size of dataset 2
    datasets:
    # SA1B as an example of an image dataset
    - _target_: training.dataset.vos_dataset.VOSDataset
      training: true
      video_dataset:
        _target_: training.dataset.vos_raw_dataset.SA1BRawDataset
        img_folder: ${path_to_img_folder}
        gt_folder: ${path_to_gt_folder}
        file_list_txt: ${path_to_train_filelist} # Optional
      sampler:
        _target_: training.dataset.vos_sampler.RandomUniformSampler
        num_frames: 1
        max_num_objects: ${max_num_objects_per_image}
      transforms: ${image_transforms}
    # SA-V as an example of a video dataset
    - _target_: training.dataset.vos_dataset.VOSDataset
      training: true
      video_dataset:
        _target_: training.dataset.vos_raw_dataset.JSONRawDataset
        img_folder: ${path_to_img_folder}
        gt_folder: ${path_to_gt_folder}
        file_list_txt: ${path_to_train_filelist} # Optional
        ann_every: 4
      sampler:
        _target_: training.dataset.vos_sampler.RandomUniformSampler
        num_frames: 8 # Number of frames per video
        max_num_objects: ${max_num_objects_per_video}
        reverse_time_prob: ${reverse_time_prob} # probability to reverse video
      transforms: ${video_transforms}
    shuffle: True
    num_workers: ${num_train_workers}
    pin_memory: True
    drop_last: True
    collate_fn:
    _target_: training.utils.data_utils.collate_fn
    _partial_: true
    dict_key: all
```

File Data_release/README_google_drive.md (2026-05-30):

# Airscope Google Drive Data Release

This Google Drive folder contains the code, released datasets, raw recordings,
model resources, and supporting files associated with the Airscope release.

Public Drive folder:
<https://drive.google.com/drive/folders/1z9ibX8Ob2NnCdjQDHI7Z4tdhdspn647B>

Associated manuscript:

> Deciphering cortex-wide neural dynamics of naturally behaving mice by a
> 1-gram wireless mesoscope

## Top-Level Contents

| Folder or file | Description |
| --- | --- |
| `code/` | Airscope toolbox source files, including hardware designs, firmware, acquisition software, processing pipelines, and documentation. |
| `enriched_habitat/` | Single-animal Airscope recording in a 5 m2 naturalistic habitat, with synchronized multi-view behaviour videos, neural-behaviour aligned data, detection boxes, and arena annotations. |
| `Multi_animal_interaction/` | Multi-animal Airscope recording with behaviour video, SAM2 instance masks, aligned neural activity, cortical labels, neuron centres, and mouse trajectories. |
| `MCU_timestamps/` | Microcontroller timestamp files used to validate Airscope frame rate and acquisition timing. |
| `raw_recordings/` | Raw Airscope recording files and related acquisition outputs. |
| `SAM2_Mice/` | SAM2Mice demo data, benchmark data, model checkpoints, and YOLO prompt-generation resources. |
| `README_google_drive.md` | This file. |

## Recommended Local Layout

After downloading the folders that you need, keep the same directory names when
possible:

```text
Airscope/
├── code/
├── enriched_habitat/
├── Multi_animal_interaction/
├── MCU_timestamps/
├── raw_recordings/
└── SAM2_Mice/
```

The notebooks in the code release assume that downloaded data are either placed
next to the notebook or that the path configuration cell is updated to point to
the downloaded folder.

## Released Datasets

### `enriched_habitat/`

This dataset contains a single-animal Airscope recording in a 5 m2 naturalistic
habitat.

Main files:

- `data_aligned.mat`: calcium traces aligned to behaviour timestamps, cortical
  labels, and neuron centroid coordinates.
- `video/`: synchronized behaviour videos from top-down and side-view cameras.
- `detection_box.json`: mouse detection bounding boxes for behaviour-video
  frames.
- `CD00362AAK00005_0000.json`: LabelMe annotation file for top-down arena
  regions.
- `README.md`: dataset-level variable descriptions and loading examples.

### `Multi_animal_interaction/`

This dataset contains a multi-animal Airscope recording with aligned neural and
behavioural measurements.

Main files:

- `data_aligned.mat`: aligned calcium traces, cortical labels, neuron centres,
  and behaviour-derived mouse centres.
- `behavior.mp4`: raw multi-animal behaviour video.
- `behavior_with_mask.avi`: behaviour video with SAM2 instance masks overlaid.
- `segment_mask.pickle`: gzip-compressed pickle file containing packed SAM2
  binary masks for each video frame.
- `README.md`: dataset-level variable descriptions, mask loading examples, and
  video metadata.

### `MCU_timestamps/`

This folder contains timestamp text files recorded by the Airscope
microcontroller. These files are used to estimate the actual imaging frame rate
and check acquisition timing stability.

### `raw_recordings/`

This folder contains raw acquisition outputs. These files are provided for
users who need to inspect or reprocess data from earlier stages of the Airscope
workflow.

## Code and Analysis

The `code/` folder contains the Airscope toolbox. The main modules are:

- hardware design files: mechanical CAD, optical design, and electronics;
- firmware for Airscope device control and image acquisition;
- host acquisition software for device discovery, preview, timestamping, and
  recording;
- calcium-imaging processing pipeline;
- SAM2Mice behavioural segmentation and tracking tools;
- Neuron-BERT neural decoding models.

For the latest repository documentation, see the root `README.md` in the code
folder.

## SAM2Mice Resources

The `SAM2_Mice/` folder contains data and resources for mouse segmentation and
tracking workflows, including benchmark datasets, demonstration data, model
checkpoints, and YOLO training or prompt-generation resources.

Use the SAM2Mice README and notebooks in the code release for installation and
workflow details.

## Licensing and Citation

Unless otherwise noted, released data, dataset documentation, figures, and
visualization notebooks are distributed under the Creative Commons Attribution
4.0 International License (CC-BY-4.0).

If you use Airscope hardware files, software, or released data, please cite:

```bibtex
@article{airscope2025,
  title   = {Deciphering cortex-wide neural dynamics of naturally
             behaving mice by a 1-gram wireless mesoscope},
  author  = {Zhang, Yuanlong and Li, Angran and Yuan, Lekang and
             Wang, Mingrui and Zhao, Weihao and Wang, Zhenbo and
             Zang, Boyang and Zhou, Yangxuan and Yu, Tao and Gao, Lin
             and Wu, Yu and Zhu, Rongkang and Tian, Mengyi and Li, Kun
             and Wu, Jiamin and Dai, Pu and Dai, Qionghai},
  journal = {Nature},
  year    = {2025},
  note    = {Manuscript in preparation}
}
```

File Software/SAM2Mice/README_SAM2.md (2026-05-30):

# SAM 2: Segment Anything in Images and Videos

**[AI at Meta, FAIR](https://ai.meta.com/research/)**

[Nikhila Ravi](https://nikhilaravi.com/), [Valentin Gabeur](https://gabeur.github.io/), [Yuan-Ting Hu](https://scholar.google.com/citations?user=E8DVVYQAAAAJ&hl=en), [Ronghang Hu](https://ronghanghu.com/), [Chaitanya Ryali](https://scholar.google.com/citations?user=4LWx24UAAAAJ&hl=en), [Tengyu Ma](https://scholar.google.com/citations?user=VeTSl0wAAAAJ&hl=en), [Haitham Khedr](https://hkhedr.com/), [Roman Rädle](https://scholar.google.de/citations?user=Tpt57v0AAAAJ&hl=en), [Chloe Rolland](https://scholar.google.com/citations?hl=fr&user=n-SnMhoAAAAJ), [Laura Gustafson](https://scholar.google.com/citations?user=c8IpF9gAAAAJ&hl=en), [Eric Mintun](https://ericmintun.github.io/), [Junting Pan](https://junting.github.io/), [Kalyan Vasudev Alwala](https://scholar.google.co.in/citations?user=m34oaWEAAAAJ&hl=en), [Nicolas Carion](https://www.nicolascarion.com/), [Chao-Yuan Wu](https://chaoyuan.org/), [Ross Girshick](https://www.rossgirshick.info/), [Piotr Dollár](https://pdollar.github.io/), [Christoph Feichtenhofer](https://feichtenhofer.github.io/)

[[`Paper`](https://ai.meta.com/research/publications/sam-2-segment-anything-in-images-and-videos/)] [[`Project`](https://ai.meta.com/sam2)] [[`Demo`](https://sam2.metademolab.com/)] [[`Dataset`](https://ai.meta.com/datasets/segment-anything-video)] [[`Blog`](https://ai.meta.com/blog/segment-anything-2)] [[`BibTeX`](#citing-sam-2)]

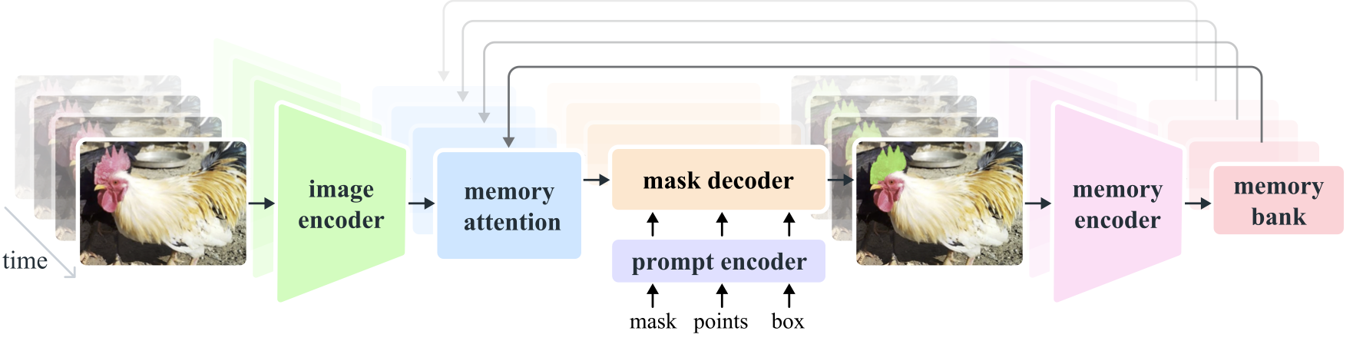
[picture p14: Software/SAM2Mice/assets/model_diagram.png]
SAM 2 architecture


**Segment Anything Model 2 (SAM 2)** is a foundation model towards solving promptable visual segmentation in images and videos. We extend SAM to video by considering images as a video with a single frame. The model design is a simple transformer architecture with streaming memory for real-time video processing. We build a model-in-the-loop data engine, which improves model and data via user interaction, to collect [**our SA-V dataset**](https://ai.meta.com/datasets/segment-anything-video), the largest video segmentation dataset to date. SAM 2 trained on our data provides strong performance across a wide range of tasks and visual domains.

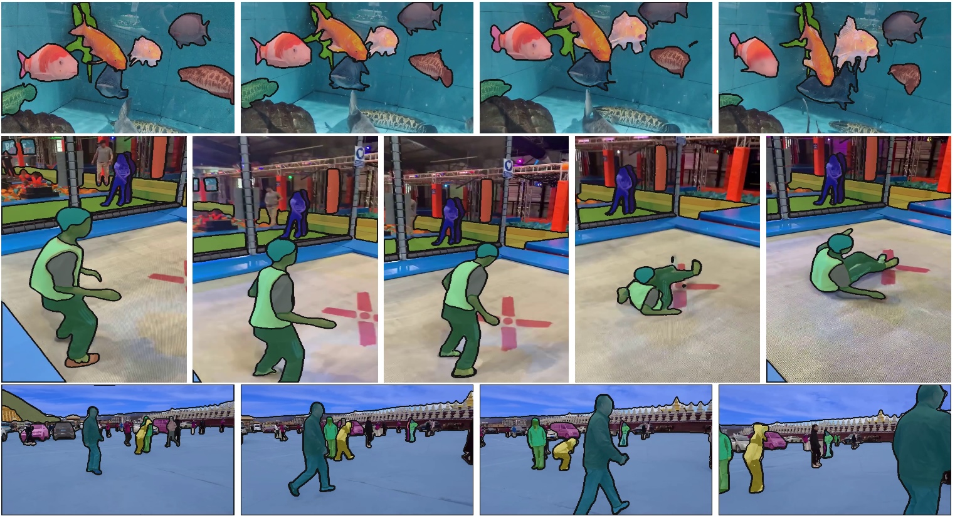
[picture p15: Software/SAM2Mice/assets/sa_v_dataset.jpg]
SA-V dataset


## Latest updates

**12/11/2024 -- full model compilation for a major VOS speedup and a new `SAM2VideoPredictor` to better handle multi-object tracking**

- We now support `torch.compile` of the entire SAM 2 model on videos, which can be turned on by setting `vos_optimized=True` in `build_sam2_video_predictor`, leading to a major speedup for VOS inference.
- We update the implementation of `SAM2VideoPredictor` to support independent per-object inference, allowing us to relax the assumption of prompting for multi-object tracking and adding new objects after tracking starts.
- See [`RELEASE_NOTES.md`](RELEASE_NOTES.md) for full details.

**09/30/2024 -- SAM 2.1 Developer Suite (new checkpoints, training code, web demo) is released**

- A new suite of improved model checkpoints (denoted as **SAM 2.1**) are released. See [Model Description](#model-description) for details.
  * To use the new SAM 2.1 checkpoints, you need the latest model code from this repo. If you have installed an earlier version of this repo, please first uninstall the previous version via `pip uninstall SAM-2`, pull the latest code from this repo (with `git pull`), and then reinstall the repo following [Installation](#installation) below.
- The training (and fine-tuning) code has been released. See [`training/README.md`](training/README.md) on how to get started.
- The frontend + backend code for the SAM 2 web demo has been released. See [`demo/README.md`](demo/README.md) for details.

## Installation

SAM 2 needs to be installed first before use. The code requires `python>=3.10`, as well as `torch>=2.5.1` and `torchvision>=0.20.1`. Please follow the instructions [here](https://pytorch.org/get-started/locally/) to install both PyTorch and TorchVision dependencies. You can install SAM 2 on a GPU machine using:

```bash
git clone https://github.com/facebookresearch/sam2.git && cd sam2

pip install -e .
```
If you are installing on Windows, it's strongly recommended to use [Windows Subsystem for Linux (WSL)](https://learn.microsoft.com/en-us/windows/wsl/install) with Ubuntu.

To use the SAM 2 predictor and run the example notebooks, `jupyter` and `matplotlib` are required and can be installed by:

```bash
pip install -e ".[notebooks]"
```

Note:
1. It's recommended to create a new Python environment via [Anaconda](https://www.anaconda.com/) for this installation and install PyTorch 2.5.1 (or higher) via `pip` following https://pytorch.org/. If you have a PyTorch version lower than 2.5.1 in your current environment, the installation command above will try to upgrade it to the latest PyTorch version using `pip`.
2. The step above requires compiling a custom CUDA kernel with the `nvcc` compiler. If it isn't already available on your machine, please install the [CUDA toolkits](https://developer.nvidia.com/cuda-toolkit-archive) with a version that matches your PyTorch CUDA version.
3. If you see a message like `Failed to build the SAM 2 CUDA extension` during installation, you can ignore it and still use SAM 2 (some post-processing functionality may be limited, but it doesn't affect the results in most cases).

Please see [`INSTALL.md`](./INSTALL.md) for FAQs on potential issues and solutions.

## Getting Started

### Download Checkpoints

First, we need to download a model checkpoint. All the model checkpoints can be downloaded by running:

```bash
cd checkpoints && \
./download_ckpts.sh && \
cd ..
```

or individually from:

- [sam2.1_hiera_tiny.pt](https://dl.fbaipublicfiles.com/segment_anything_2/092824/sam2.1_hiera_tiny.pt)
- [sam2.1_hiera_small.pt](https://dl.fbaipublicfiles.com/segment_anything_2/092824/sam2.1_hiera_small.pt)
- [sam2.1_hiera_base_plus.pt](https://dl.fbaipublicfiles.com/segment_anything_2/092824/sam2.1_hiera_base_plus.pt)
- [sam2.1_hiera_large.pt](https://dl.fbaipublicfiles.com/segment_anything_2/092824/sam2.1_hiera_large.pt)

(note that these are the improved checkpoints denoted as SAM 2.1; see [Model Description](#model-description) for details.)

Then SAM 2 can be used in a few lines as follows for image and video prediction.

### Image prediction

SAM 2 has all the capabilities of [SAM](https://github.com/facebookresearch/segment-anything) on static images, and we provide image prediction APIs that closely resemble SAM for image use cases. The `SAM2ImagePredictor` class has an easy interface for image prompting.

```python
import torch
from sam2.build_sam import build_sam2
from sam2.sam2_image_predictor import SAM2ImagePredictor

checkpoint = "./checkpoints/sam2.1_hiera_large.pt"
model_cfg = "configs/sam2.1/sam2.1_hiera_l.yaml"
predictor = SAM2ImagePredictor(build_sam2(model_cfg, checkpoint))

with torch.inference_mode(), torch.autocast("cuda", dtype=torch.bfloat16):
    predictor.set_image(<your_image>)
    masks, _, _ = predictor.predict(<input_prompts>)
```

Please refer to the examples in [image_predictor_example.ipynb](./notebooks/image_predictor_example.ipynb) (also in Colab [here](https://colab.research.google.com/github/facebookresearch/sam2/blob/main/notebooks/image_predictor_example.ipynb)) for static image use cases.

SAM 2 also supports automatic mask generation on images just like SAM. Please see [automatic_mask_generator_example.ipynb](./notebooks/automatic_mask_generator_example.ipynb) (also in Colab [here](https://colab.research.google.com/github/facebookresearch/sam2/blob/main/notebooks/automatic_mask_generator_example.ipynb)) for automatic mask generation in images.

### Video prediction

For promptable segmentation and tracking in videos, we provide a video predictor with APIs for example to add prompts and propagate masklets throughout a video. SAM 2 supports video inference on multiple objects and uses an inference state to keep track of the interactions in each video.

```python
import torch
from sam2.build_sam import build_sam2_video_predictor

checkpoint = "./checkpoints/sam2.1_hiera_large.pt"
model_cfg = "configs/sam2.1/sam2.1_hiera_l.yaml"
predictor = build_sam2_video_predictor(model_cfg, checkpoint)

with torch.inference_mode(), torch.autocast("cuda", dtype=torch.bfloat16):
    state = predictor.init_state(<your_video>)

    # add new prompts and instantly get the output on the same frame
    frame_idx, object_ids, masks = predictor.add_new_points_or_box(state, <your_prompts>):

    # propagate the prompts to get masklets throughout the video
    for frame_idx, object_ids, masks in predictor.propagate_in_video(state):
        ...
```

Please refer to the examples in [video_predictor_example.ipynb](./notebooks/video_predictor_example.ipynb) (also in Colab [here](https://colab.research.google.com/github/facebookresearch/sam2/blob/main/notebooks/video_predictor_example.ipynb)) for details on how to add click or box prompts, make refinements, and track multiple objects in videos.

## Load from 🤗 Hugging Face

Alternatively, models can also be loaded from [Hugging Face](https://huggingface.co/models?search=facebook/sam2) (requires `pip install huggingface_hub`).

For image prediction:

```python
import torch
from sam2.sam2_image_predictor import SAM2ImagePredictor

predictor = SAM2ImagePredictor.from_pretrained("facebook/sam2-hiera-large")

with torch.inference_mode(), torch.autocast("cuda", dtype=torch.bfloat16):
    predictor.set_image(<your_image>)
    masks, _, _ = predictor.predict(<input_prompts>)
```

For video prediction:

```python
import torch
from sam2.sam2_video_predictor import SAM2VideoPredictor

predictor = SAM2VideoPredictor.from_pretrained("facebook/sam2-hiera-large")

with torch.inference_mode(), torch.autocast("cuda", dtype=torch.bfloat16):
    state = predictor.init_state(<your_video>)

    # add new prompts and instantly get the output on the same frame
    frame_idx, object_ids, masks = predictor.add_new_points_or_box(state, <your_prompts>):

    # propagate the prompts to get masklets throughout the video
    for frame_idx, object_ids, masks in predictor.propagate_in_video(state):
        ...
```

## Model Description

### SAM 2.1 checkpoints

The table below shows the improved SAM 2.1 checkpoints released on September 29, 2024.
| **Model** | **Size (M)** | **Speed (FPS)** | **SA-V test (J&F)** | **MOSE val (J&F)** | **LVOS v2 (J&F)** |
| :---: | :---: | :---: | :---: | :---: | :---: |
| sam2.1_hiera_tiny <br /> ([config](sam2/configs/sam2.1/sam2.1_hiera_t.yaml), [checkpoint](https://dl.fbaipublicfiles.com/segment_anything_2/092824/sam2.1_hiera_tiny.pt)) | 38.9 | 91.2 | 76.5 | 71.8 | 77.3 |
| sam2.1_hiera_small <br /> ([config](sam2/configs/sam2.1/sam2.1_hiera_s.yaml), [checkpoint](https://dl.fbaipublicfiles.com/segment_anything_2/092824/sam2.1_hiera_small.pt)) | 46 | 84.8 | 76.6 | 73.5 | 78.3 |
| sam2.1_hiera_base_plus <br /> ([config](sam2/configs/sam2.1/sam2.1_hiera_b+.yaml), [checkpoint](https://dl.fbaipublicfiles.com/segment_anything_2/092824/sam2.1_hiera_base_plus.pt)) | 80.8 | 64.1 | 78.2 | 73.7 | 78.2 |
| sam2.1_hiera_large <br /> ([config](sam2/configs/sam2.1/sam2.1_hiera_l.yaml), [checkpoint](https://dl.fbaipublicfiles.com/segment_anything_2/092824/sam2.1_hiera_large.pt)) | 224.4 | 39.5 | 79.5 | 74.6 | 80.6 |

### SAM 2 checkpoints

The previous SAM 2 checkpoints released on July 29, 2024 can be found as follows:

| **Model** | **Size (M)** | **Speed (FPS)** | **SA-V test (J&F)** | **MOSE val (J&F)** | **LVOS v2 (J&F)** |
| :---: | :---: | :---: | :---: | :---: | :---: |
| sam2_hiera_tiny <br /> ([config](sam2/configs/sam2/sam2_hiera_t.yaml), [checkpoint](https://dl.fbaipublicfiles.com/segment_anything_2/072824/sam2_hiera_tiny.pt)) | 38.9 | 91.5 | 75.0 | 70.9 | 75.3 |
| sam2_hiera_small <br /> ([config](sam2/configs/sam2/sam2_hiera_s.yaml), [checkpoint](https://dl.fbaipublicfiles.com/segment_anything_2/072824/sam2_hiera_small.pt)) | 46 | 85.6 | 74.9 | 71.5 | 76.4 |
| sam2_hiera_base_plus <br /> ([config](sam2/configs/sam2/sam2_hiera_b+.yaml), [checkpoint](https://dl.fbaipublicfiles.com/segment_anything_2/072824/sam2_hiera_base_plus.pt)) | 80.8 | 64.8 | 74.7 | 72.8 | 75.8 |
| sam2_hiera_large <br /> ([config](sam2/configs/sam2/sam2_hiera_l.yaml), [checkpoint](https://dl.fbaipublicfiles.com/segment_anything_2/072824/sam2_hiera_large.pt)) | 224.4 | 39.7 | 76.0 | 74.6 | 79.8 |

Speed measured on an A100 with `torch 2.5.1, cuda 12.4`. See `benchmark.py` for an example on benchmarking (compiling all the model components). Compiling only the image encoder can be more flexible and also provide (a smaller) speed-up (set `compile_image_encoder: True` in the config).
## Segment Anything Video Dataset

See [sav_dataset/README.md](sav_dataset/README.md) for details.

## Training SAM 2

You can train or fine-tune SAM 2 on custom datasets of images, videos, or both. Please check the training [README](training/README.md) on how to get started.

## Web demo for SAM 2

We have released the frontend + backend code for the SAM 2 web demo (a locally deployable version similar to https://sam2.metademolab.com/demo). Please see the web demo [README](demo/README.md) for details.

## License

The Airscope release of SAM2Mice software is distributed under the GNU General Public License v3.0 only. See [LICENSE](./LICENSE). Third-party assets and dependencies retain their own license terms; for example, the [Inter Font](https://github.com/rsms/inter?tab=OFL-1.1-1-ov-file) and [Noto Color Emoji](https://github.com/googlefonts/noto-emoji) used in the SAM 2 demo code are made available under the [SIL Open Font License, version 1.1](https://openfontlicense.org/open-font-license-official-text/).

## Contributing

See [contributing](CONTRIBUTING.md) and the [code of conduct](CODE_OF_CONDUCT.md).

## Contributors

The SAM 2 project was made possible with the help of many contributors (alphabetical):

Karen Bergan, Daniel Bolya, Alex Bosenberg, Kai Brown, Vispi Cassod, Christopher Chedeau, Ida Cheng, Luc Dahlin, Shoubhik Debnath, Rene Martinez Doehner, Grant Gardner, Sahir Gomez, Rishi Godugu, Baishan Guo, Caleb Ho, Andrew Huang, Somya Jain, Bob Kamma, Amanda Kallet, Jake Kinney, Alexander Kirillov, Shiva Koduvayur, Devansh Kukreja, Robert Kuo, Aohan Lin, Parth Malani, Jitendra Malik, Mallika Malhotra, Miguel Martin, Alexander Miller, Sasha Mitts, William Ngan, George Orlin, Joelle Pineau, Kate Saenko, Rodrick Shepard, Azita Shokrpour, David Soofian, Jonathan Torres, Jenny Truong, Sagar Vaze, Meng Wang, Claudette Ward, Pengchuan Zhang.

Third-party code: we use a GPU-based connected component algorithm adapted from [`cc_torch`](https://github.com/zsef123/Connected_components_PyTorch) (with its license in [`LICENSE_cctorch`](./LICENSE_cctorch)) as an optional post-processing step for the mask predictions.

## Citing SAM 2

If you use SAM 2 or the SA-V dataset in your research, please use the following BibTeX entry.

```bibtex
@article{ravi2024sam2,
  title={SAM 2: Segment Anything in Images and Videos},
  author={Ravi, Nikhila and Gabeur, Valentin and Hu, Yuan-Ting and Hu, Ronghang and Ryali, Chaitanya and Ma, Tengyu and Khedr, Haitham and R{\"a}dle, Roman and Rolland, Chloe and Gustafson, Laura and Mintun, Eric and Pan, Junting and Alwala, Kalyan Vasudev and Carion, Nicolas and Wu, Chao-Yuan and Girshick, Ross and Doll{\'a}r, Piotr and Feichtenhofer, Christoph},
  journal={arXiv preprint arXiv:2408.00714},
  url={https://arxiv.org/abs/2408.00714},
  year={2024}
}
```

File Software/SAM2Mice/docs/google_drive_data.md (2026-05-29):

# Google Drive Data

All shared SAM2Mice data is hosted in a single Google Drive folder:

**Root:** https://drive.google.com/drive/folders/1h3JZ6n-LhZRwAsLCKLH60XWioy7f3WPZ

The structure below was parsed from the public Google Drive folder listing with `gdown` on 2026-05-29. Large frame/label folders are summarized by pattern and count.

---

## Folder structure

```
SAM2_Mice/
|
├── benchmark_data/
|   ├── DLC_trained_output/
|   |   ├── plot-poses/
|   |   |   └── openfield_five_mouse/
|   |   ├── openfield_five_mouse.mp4
|   |   ├── openfield_five_mouseDLC_*_assemblies.pickle
|   |   ├── openfield_five_mouseDLC_*_el.csv
|   |   ├── openfield_five_mouseDLC_*_el.h5
|   |   ├── openfield_five_mouseDLC_*_el.pickle
|   |   ├── openfield_five_mouseDLC_*_el_filtered.csv
|   |   ├── openfield_five_mouseDLC_*_el_filtered.h5
|   |   ├── openfield_five_mouseDLC_*_el_filtered_id_labeled.mp4
|   |   ├── openfield_five_mouseDLC_*_full.pickle
|   |   └── openfield_five_mouseDLC_*_meta.pickle
|   ├── ground_truth_bb_labels/
|   |   └── 00000.txt ... 01000.txt                       # 1001 files
|   ├── openfield_five_mouse/
|   |   ├── 00000.jpg ... 00999.jpg                       # 1000 frame files
|   |   └── 00000.json                                    # prompt JSON
|   ├── openfield_five_mouse_seg/
|   |   ├── frames/                                       # 1000 jpg files
|   |   ├── prompts/                                      # 1 file
|   |   ├── SAM2Mice_label_vis/                           # 1001 jpg files
|   |   ├── SAM2Mice_yolo_labels/                         # 1001 txt files
|   |   ├── segment_masks.pickle
|   |   └── segmented_video.mp4
|   └── SuperAnimal_output/
|       ├── openfield_five_mouse_superanimal_*.h5
|       ├── openfield_five_mouse_superanimal_*_before_adapt.json
|       └── openfield_five_mouse_superanimal_*_labeled_before_adapt.mp4
|
├── ckpt/
|   ├── SAM2_Mice_base_plus.pt
|   └── yolo11l_openfield_five_mice.pt
|
├── demo_data/
|   ├── 1_habitat_ultra/                                  # Notebook 01
|   |   ├── habitat_ultra_seg/                            # listing returned 401
|   |   ├── prompts/
|   |   |   ├── 00000.json
|   |   |   └── 00009.json
|   |   └── habitat_ultra.mp4
|   ├── 2_auto_prompt/                                    # Notebook 01
|   |   └── openfield_three_mouse.mp4
|   ├── 3_bootstrapping/                                  # Notebook 02
|   |   ├── prompts/
|   |   |   └── 00000.json
|   |   └── openfield_five_mouse.mp4
|   ├── 4_dynamic_id/                                     # Notebook 03
|   |   └── three_mice_sequence.mp4
|   ├── 5_zero_shot_web_dataset/                          # Notebook 04
|   |   ├── 012609_A29_Block11_ovtBCfe1_t_505_6753.mp4
|   |   ├── 012609_A29_Block11_ovtBCfe1_t_505_6753_00000.jpg
|   |   ├── 012609_A29_Block11_ovtBCfe1_t_505_6753_00000.json
|   |   ├── 20080321162447_first5min.mp4
|   |   ├── 20080321162447_first5min_00000.jpg
|   |   ├── 20080321162447_first5min_00000.json
|   |   ├── OFT_5.mp4
|   |   ├── OFT_5_00100.jpg
|   |   └── OFT_5_00100.json
|   └── 6_example_dataset.zip                             # Notebook 05
|
└── YOLO_data/
    ├── images/
    |   ├── train/                                        # 1470 jpg files
    |   ├── train_vis/                                    # 1470 jpg files
    |   └── val/                                          # 164 jpg files
    └── labels/
        ├── train/                                        # 1470 txt files
        ├── val/                                          # 164 txt files
        ├── train.cache
        └── val.cache
```

---

## Demo download summary

| Notebook | Folder | Files downloaded |
|---|---|---|
| 01 | `demo_data/1_habitat_ultra/` | `habitat_ultra.mp4` |
| 01 | `demo_data/1_habitat_ultra/prompts/` | prompt JSONs |
| 01 | `demo_data/2_auto_prompt/` | `openfield_three_mouse.mp4` |
| 02 | `demo_data/3_bootstrapping/` | `openfield_five_mouse.mp4` |
| 02 | `demo_data/3_bootstrapping/prompts/` | prompt JSONs |
| 03 | `demo_data/4_dynamic_id/` | `three_mice_sequence.mp4` |
| 04 | `demo_data/5_zero_shot_web_dataset/` | 3 videos + 3 images + 3 prompt JSONs |
| 05 | `demo_data/` | `6_example_dataset.zip` |

---

## Manual download

To download all data at once, open the root folder link above and use **Download all** in Google Drive, or use `gdown` per-item as shown in each notebook's first cell.

Single file:
```bash
gdown https://drive.google.com/uc?id=<file_id> -O <destination>
```

Folder:
```bash
gdown --folder https://drive.google.com/drive/folders/<folder_id> -O <destination> --remaining-ok
```

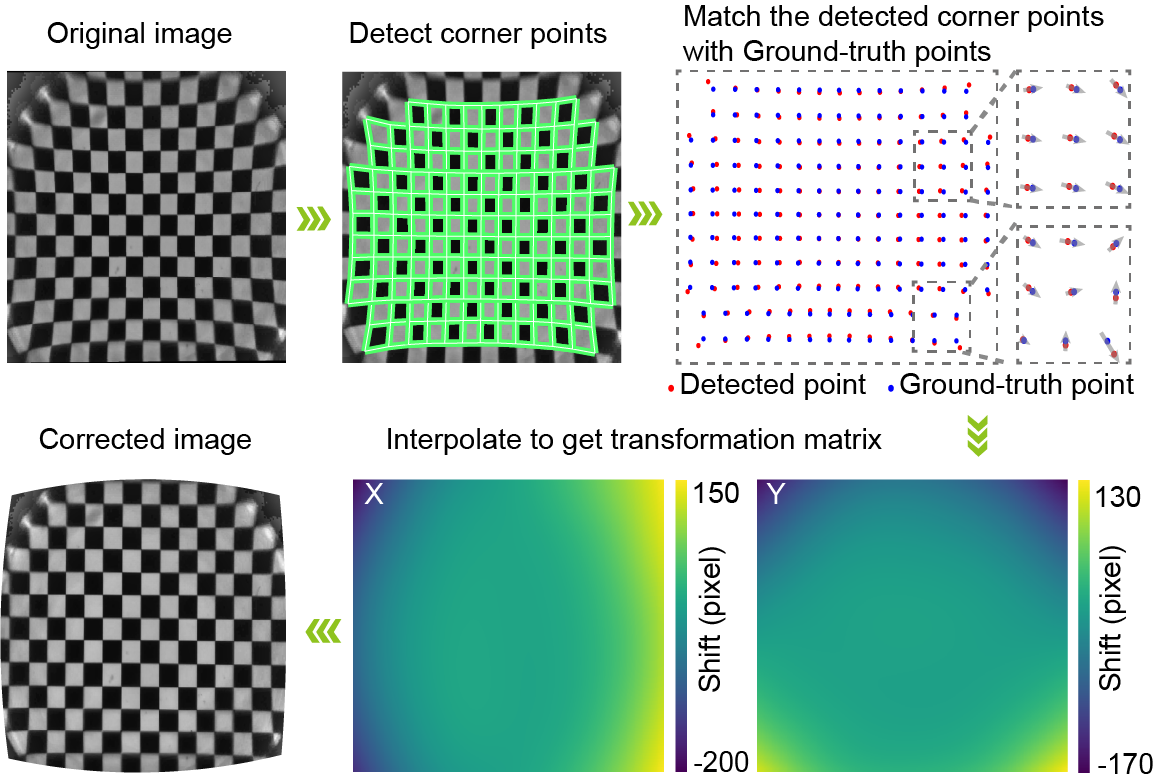
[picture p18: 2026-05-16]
Software/Airscope_ca_processing/assets/correction.png

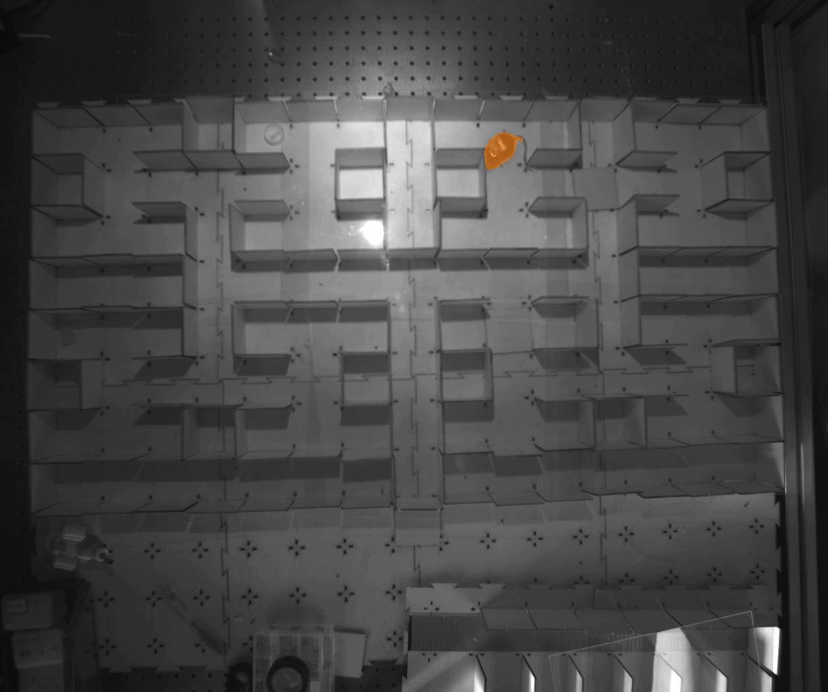
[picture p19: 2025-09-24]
Software/SAM2Mice/notebooks/images/00265_mask.jpg

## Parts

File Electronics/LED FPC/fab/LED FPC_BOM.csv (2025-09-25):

Comment | Description | Designator | Footprint | LibRef | Pins | Quantity | PartNumber | url
BM29B-2DP_2-0.35V_51_ | desc | J1, | BM29B-2DP_2-0.35V_51__HRS_BM29B-2DP_2-0.35V_51_ | libref | 6 | 1
LXZ1-PB01 | desc | U1,U2,U3,U4, | LXZ1-PB01 | libref | 2 | 4
Pad1 | desc | U5,U6, | Rec_Pad_1 | libref | 1 | 2

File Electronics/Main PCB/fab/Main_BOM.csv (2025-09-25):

Comment | Description | Designator | Footprint | LibRef | Pins | Quantity | PartNumber | url
0.1u | desc | C1,C7, | C_0201_Metric | libref | 4 | 2
10u | desc | C3, | C_0603_Metric | libref | 2 | 1
DF40C-20DP-0.4V_51_ | desc | J1, | HRS_DF40C-20DP-0.4V_51_ | libref | 24 | 1
BM29B0.6-2DS_2-0.35V_51_ | desc | J2, | BM29B0.6-2DS_2-0.35V_51__HRS_BM29B0.6-2DS_2-0.35V_51_ | libref | 10 | 1
4.7k | desc | R1,R2,R3,R4, | R_0201_Metric | libref | 4 | 4
AN2051-245 | desc | U1, | AN2051 | libref | 2 | 1
ESP32-PICO-V3-02 | desc | U2, | Pico-QFN-48 | libref | 65 | 1
0.1u | desc | C2,C6,C8, | C_0201_Metric | libref | 4 | 3
15p | desc | C9, | C_0201_Metric | libref | 4 | 1
1u | desc | C10,C11,C12,C13,C14, | C_0201_Metric | libref | 4 | 5
BM29B0.6-2DS_2-0.35V_51_ | desc | J3, | BM29B0.6-2DS_2-0.35V_51__HRS_BM29B0.6-2DS_2-0.35V_51_ | libref | 10 | 1
4.7k | desc | R5,R6,R7,R8,R9, | R_0201_Metric | libref | 4 | 5
OV2640 | desc | U3, | OV2640_BGA38 | libref | 38 | 1
MAX31875 | desc | U4, | BGA4N40P2X2_83X83X37N | libref | 4 | 1
PTPS7A2028PDQNR | desc | U5, | PTPS7A20185PDQNR | libref | 5 | 1
PTPS7A2015PDQNR | desc | U6, | PTPS7A20185PDQNR | libref | 5 | 1
LM36011 | desc | U7, | LM36011_BGA24 | libref | 8 | 1

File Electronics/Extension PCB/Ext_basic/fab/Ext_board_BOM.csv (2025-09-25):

Comment | Description | Designator | Footprint | LibRef | Pins | Quantity | PartNumber | url
CSNP32GCR01-AOW | desc | U1, | SD_NAND_32 | libref | 8 | 1
1u | desc | C1, | C_0402_Metric | libref | 2 | 1
DF40HC3.5-20DS-0.4V51 | desc | J1, | CONN20_DF40HC_HIR | libref | 20 | 1
10k | desc | R1,R3,R4, | R_0201_Metric | libref | 4 | 3
0 | desc | R2, | R_0201_Metric | libref | 4 | 1

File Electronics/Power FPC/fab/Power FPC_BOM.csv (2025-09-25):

Comment | Description | Designator | Footprint | LibRef | Pins | Quantity | PartNumber | url
10u | desc | C1,C3, | C_0603_Metric | libref | 2 | 2
0.1u | desc | C2, | C_0402_Metric | libref | 2 | 1
1.5u | desc | L1, | ASIC-0805F | libref | 2 | 1
TPS63031 | desc | U1, | TPS63031-10SON | libref | 11 | 1
Pad1 | desc | U2,U3,U6, | Rec_Pad_1 | libref | 1 | 3
pogo_1 | desc | U4,U5, | pogo_1 | libref | 1 | 2
BM29B-2DP_2-0.35V_51_ | desc | J1, | BM29B-2DP_2-0.35V_51__HRS_BM29B-2DP_2-0.35V_51_ | libref | 6 | 1

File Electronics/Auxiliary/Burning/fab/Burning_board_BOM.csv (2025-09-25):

Comment | Description | Designator | Footprint | LibRef | Pins | Quantity | PartNumber | url
DF40C-20DP-0.4V_51_ | desc | J1, | HRS_DF40C-20DP-0.4V_51_ | libref | 24 | 1
SM06B-SURS-TF(LF)(SN) | desc | J2, | JST_SM06B-SURS-TF(LF)(SN) | libref | 8 | 1
1u | desc | C1, | C_0402_Metric | libref | 2 | 1
DF40HC3.5-20DS-0.4V51 | desc | J3, | CONN20_DF40HC_HIR | libref | 20 | 1
Pad1 | desc | U1,U2,U3,U4, | Rec_Pad_1 | libref | 1 | 4

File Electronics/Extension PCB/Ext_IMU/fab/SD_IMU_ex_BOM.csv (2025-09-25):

Comment | Description | Designator | Footprint | LibRef | Pins | Quantity | PartNumber | url
4.7u | desc | C1, | C_0201_Metric | libref | 4 | 1
2.2u | desc | C2, | C_0201_Metric | libref | 4 | 1
4.7k | desc | R1,R2, | R_0201_Metric | libref | 4 | 2
QMC6310 | desc | U1, | QMC6310 | libref | 8 | 1
CSNP32GCR01-AOW | desc | U3, | SD_NAND_32 | libref | 8 | 1
1u | desc | C3, | C_0402_Metric | libref | 2 | 1
100n | desc | C4,C5, | C_0201_Metric | libref | 4 | 2
2.2u | desc | C6, | C_0201_Metric | libref | 4 | 1
DF40HC3.5-20DS-0.4V51 | desc | J1, | CONN20_DF40HC_HIR | libref | 20 | 1
4.7k | desc | R3,R5,R6, | R_0201_Metric | libref | 4 | 3
LSM6DSLTR | desc | U2, | LSM6DSLTR_PQFN50P300X250X86-14N | libref | 14 | 1

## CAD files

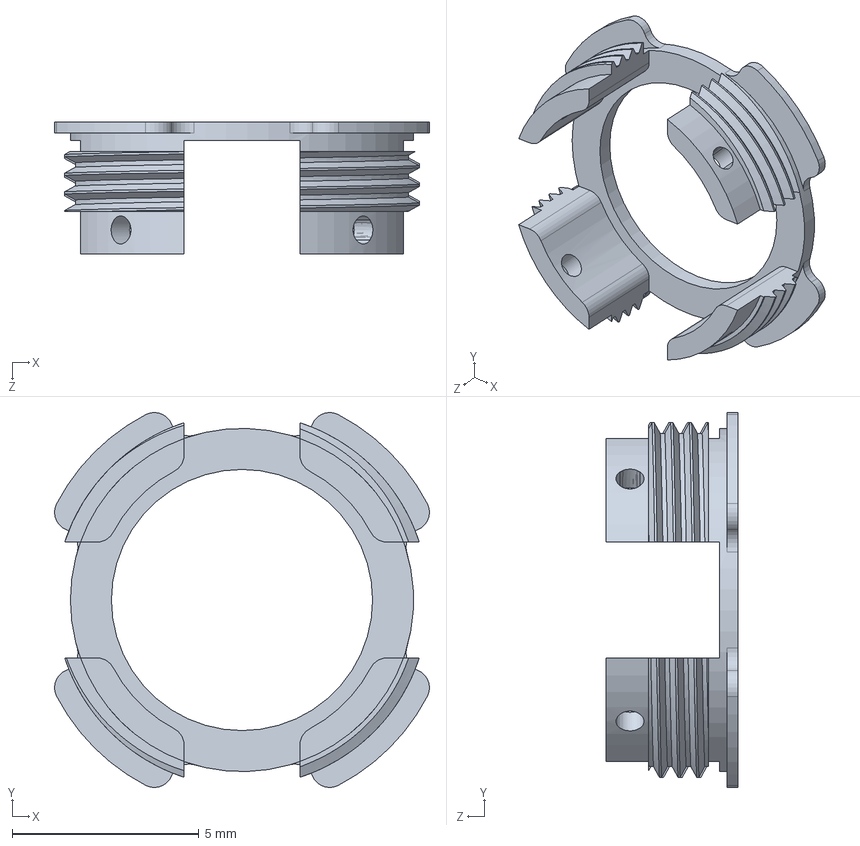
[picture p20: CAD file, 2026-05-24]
Structure/Baseplate/Rotary_version/Baseplate v2.SLDPRT
10.1 x 10.1 x 3.55 mm

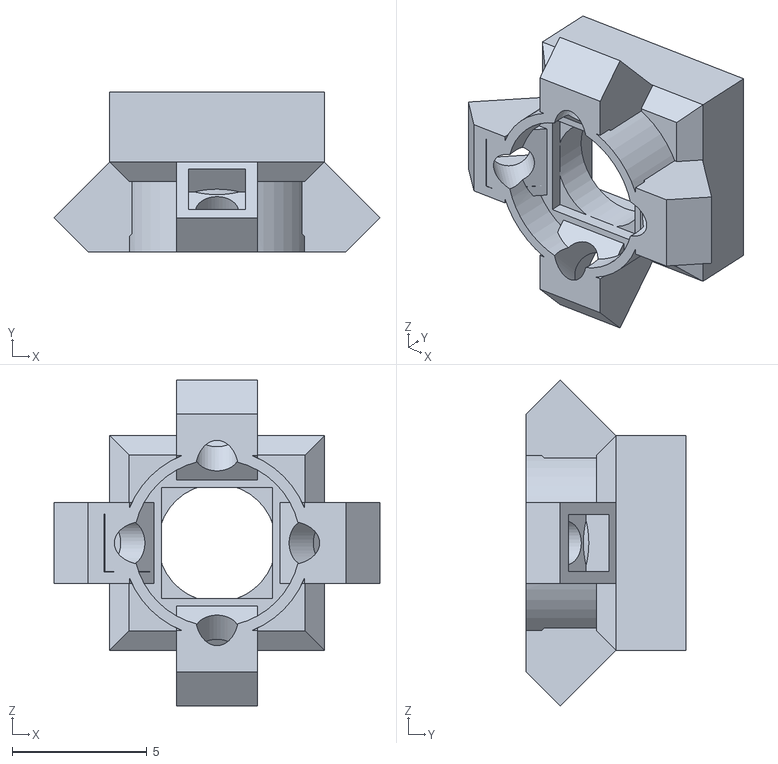
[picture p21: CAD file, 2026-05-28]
Structure/Housing/form4/stl/Housing_adjusted.STL
12.1 x 5.94 x 12.1

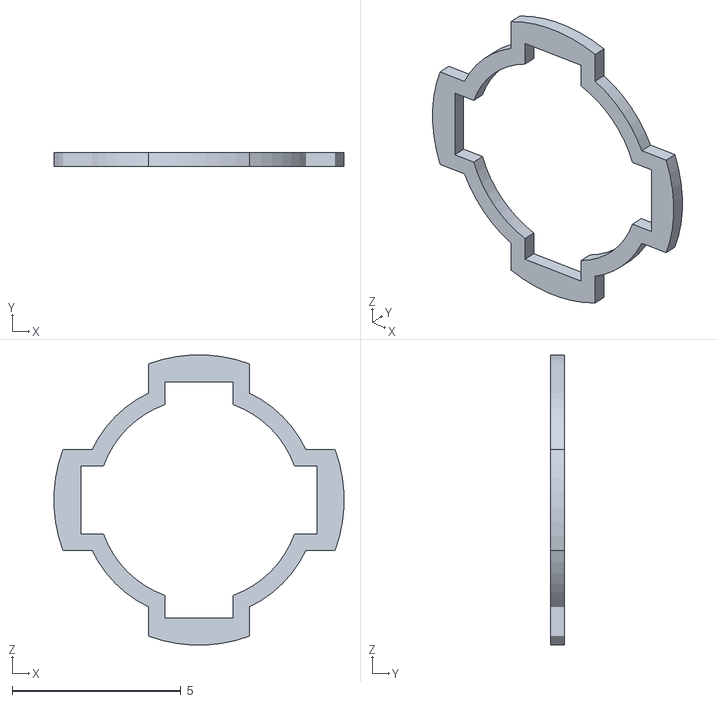
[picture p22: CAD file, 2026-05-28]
Structure/Housing/form4/stl/spacers/400.STL
8.59 x 0.4 x 8.59

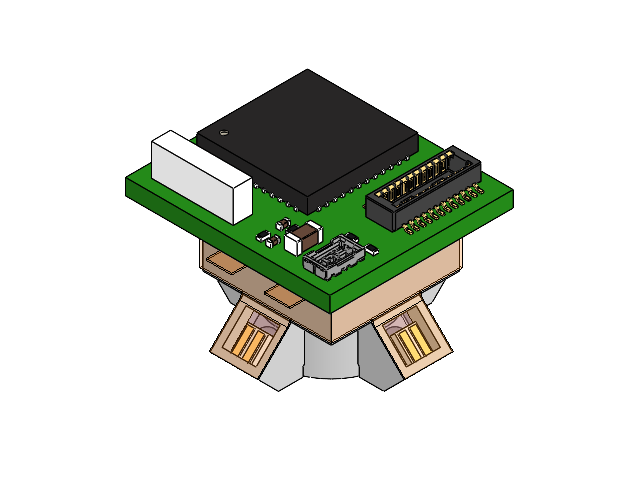
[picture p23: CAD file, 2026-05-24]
Structure/Airscope.SLDASM
Housing
Objective
Emission_filter
Excitation_filter x 4
flexible_LED_pcb2_stereo
BM29B-2DP_2-0.35V_51_
LXZ1_PB01 x 4
Pico PCB

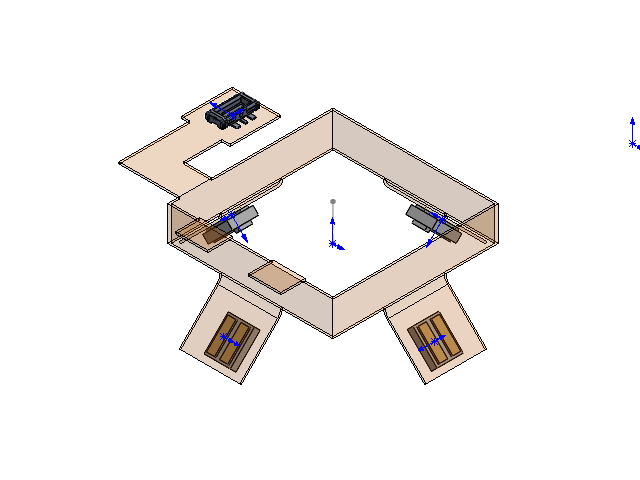
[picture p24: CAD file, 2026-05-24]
Structure/LED_FPC/FPC.SLDASM
flexible_LED_pcb2_stereo
BM29B-2DP_2-0.35V_51_
LXZ1_PB01 x 4

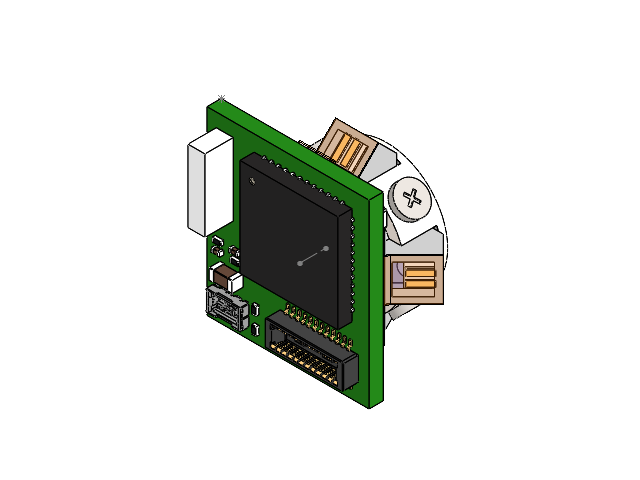
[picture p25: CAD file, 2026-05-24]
Structure/Baseplate/Spacer_version/Mounting_spacer_version.SLDASM
Base
Housing
Objective
Emission_filter
Excitation_filter x 4
flexible_LED_pcb2_stereo
BM29B-2DP_2-0.35V_51_
LXZ1_PB01 x 4
Pico PCB
spacer
M1.5_screw x 4

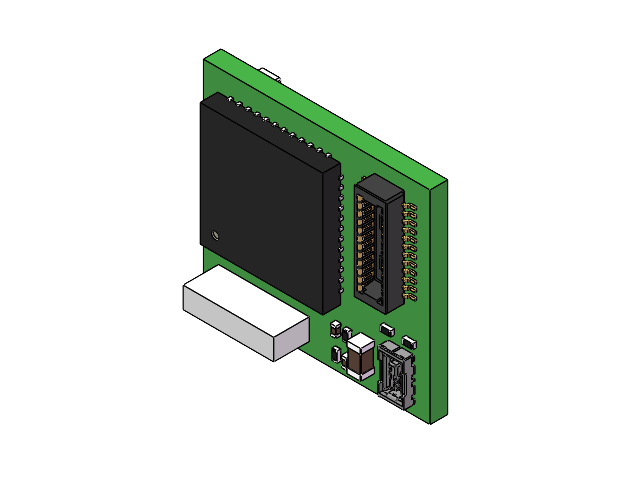
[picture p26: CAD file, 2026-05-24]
Structure/Main_PCB/Pico.SLDASM
Pico PCB

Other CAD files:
Structure/Main_PCB/DQN0004A.SLDASM
Structure/Main_PCB/DQN0004A_2.SLDASM
Structure/Main_PCB/C_0603_1608Metric.SLDASM
Structure/Main_PCB/QFN-48-1EP_7x7mm_P0.5mm_EP5.3x5.3mm.SLDASM
Structure/Main_PCB/AR0130CS.SLDASM
Structure/Main_PCB/C_0201_0603Metric.SLDASM
Structure/Main_PCB/L_Bourns_SRP2313AA.SLDASM
Structure/Main_PCB/AN2051.SLDASM
Structure/Main_PCB/BM29B0.6-2DS_2-0.35V_51_.SLDASM
Structure/Main_PCB/R_0201_0603Metric.SLDASM
Structure/Main_PCB/DF40C-20DP-0.4V_51_.SLDASM
Structure/Baseplate/Rotary_version/Focus Ring.SLDPRT
Structure/Baseplate/Rotary_version/Housing Adjusted.SLDPRT
Structure/Baseplate/Rotary_version/Locking Ring.SLDPRT
Structure/Baseplate/Spacer_version/Base.SLDPRT
Structure/Baseplate/Spacer_version/M1.5_screw.SLDPRT
Structure/Baseplate/Spacer_version/spacer.SLDPRT
Structure/Housing/Housing.SLDPRT
Structure/Housing/form4/stl/spacers/100.STL
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

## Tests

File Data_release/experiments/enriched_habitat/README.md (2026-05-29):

# Supplementary data: `5m2 natural habitat`

Release data is available in the public Airscope data release [here][release-data].

[release-data]: https://drive.google.com/drive/folders/1z9ibX8Ob2NnCdjQDHI7Z4tdhdspn647B?usp=drive_link

------------------------------------------------------------------------

## Contents of `data_aligned.mat`

-   **`timestamps`**\
    *Type:* cell array of strings (`1 × T`)\
    *Description:* Timestamps of calcium signals aligned with behavior capture.\
    *Format:* `dd-MMM-yy/HH-MM-SS-fff` (e.g.,
    `22-Jan-25/20-57-13-123`).
    
-   **`calcium_traces`**\
    *Type:* double matrix (`num_neurons × T`)\
    *Description:* Interpolated ΔF/F calcium traces, aligned to the behavior timestamps. Each column corresponds to one behavioral frame.

-   **`neuron_cortical_labels`**\
    *Type:* cell array of strings (`1 × num_neurons`)\
    *Description:* Cortical region identity of each neuron, derived from cortical alignment.

-   **`neuron_centroid_coordinates`**\
    *Type:* double matrix (`num_neurons × 2`)\
    *Description:* XY centroid coordinates of each segmented neuron in the calcium imaging field of view.\
    *Units:* pixels of Airscope calcium video.\
    *Columns:* Column 1 = X coordinate, Column 2 = Y coordinate.

------------------------------------------------------------------------
## Associated Behavioral Videos 

To complement the neural recordings, synchronized multi-view behavioral videos are provided in the `/video` directory:

-   **`CD00362AAK00005.mp4`** — Overhead (top-down) camera view of the naturalistic arena.  
-   **`AL00099B001.mp4, AL00099B003.mp4, BD03405A003.mp4, BD03405A005.mp4`** — Four lateral perspectives captured by side-mounted cameras, providing complementary information on body posture and social interaction.  

**Video specifications:** Resolution = 4096 × 3000 pixels; Frame rate = 30 fps; Format = MP4.  
All videos are time-locked to the calcium imaging data.

## Associated Annotation Files

-   **`detection_box.json`**\
    Mouse detection bounding boxes for behavior-video frames.

-   **`CD00362AAK00005_0000.json`**\
    LabelMe annotation file for the top-down camera arena regions.

## Example Usage

**MATLAB**

``` matlab
data = load('data_aligned.mat');
C = data.calcium_traces;                                
timestamps = data.time_stamps; 
regions = data.neuron_cortical_labels; 
coords = data.neuron_centroid_coordinates; 
```

**Python**

``` python
import scipy.io as sio
import os

DATA_DIR = "/path/to/natural_habitat"

ALIGNED_DATA_PATH = os.path.join(DATA_DIR, "data_aligned.mat")
BOX_PATH  = os.path.join(DATA_DIR, "detection_box.json")
LABEL_ME_REGION_PATH = os.path.join(DATA_DIR, "CD00362AAK00005_0000.json")

data = sio.loadmat(ALIGNED_DATA_PATH)

C = data["calcium_traces"]                               
timestamps = data["time_stamps"] 
regions = data["neuron_cortical_labels"] 
coords = data["neuron_centroid_coordinates"] 
```

------------------------------------------------------------------------

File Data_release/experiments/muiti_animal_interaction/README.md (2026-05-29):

# Multi-animal PICO data release

Release data is available in the public Airscope data release [here][release-data].

[release-data]: https://drive.google.com/drive/folders/1z9ibX8Ob2NnCdjQDHI7Z4tdhdspn647B?usp=drive_link

## Quick start

1. Download the released files from the Google Drive link above.
2. Put the downloaded files in one local directory. The directory should contain:
   - `behavior.mp4`
   - `behavior_with_mask.avi`
   - `segment_mask.pickle`
   - `data_aligned.mat`
3. Open `visualize_data.ipynb`.
4. In the path configuration cell, set:

```python
DATA_DIR = Path("/path/to/downloaded/multi_animal_data")
```

If the four data files are in the same directory where the notebook is running,
keep the default:

```python
DATA_DIR = Path(".")
```

5. Run the notebook cells from top to bottom. Generated figures and cached
interaction files are written to `outputs/multi_animal_interaction/`.

## Files

| File | Description |
| --- | --- |
| `behavior.mp4` | Raw multi-animal behavior video. |
| `behavior_with_mask.avi` | Behavior video with SAM2 instance masks overlaid for visual inspection. |
| `segment_mask.pickle` | Gzip-compressed pickle file containing packed binary SAM2 masks for each video frame. |
| `data_aligned.mat` | Final aligned release file. Calcium traces, cortical labels, neuron centers, and mouse mask centers are aligned to the selected behavior-frame interval. |

Video metadata for both `behavior.mp4` and `behavior_with_mask.avi`:

| Field | Value |
| --- | --- |
| Frame size | `968 x 944` pixels, width x height |
| Frame rate | `10 fps` |
| Number of frames | `10805` |
| Duration | `1080.5 s` |

## `data_aligned.mat`

The aligned interval uses behavior frames `2918` to `10518`, inclusive. The
aligned arrays therefore contain `7601` time points.

| Variable | Shape | Description |
| --- | ---: | --- |
| `start_frame` | `1 x 1` | First behavior-video frame included in the aligned interval. |
| `end_frame` | `1 x 1` | Last behavior-video frame included in the aligned interval. |
| `behavior_stamped_times_in_interval` | `7601` | Behavior timestamps for aligned frames, formatted as `DD-Mon-YY/HH-MM-SS-ffffff`. |
| `calcium_<animal>` | `n_neurons x 7601` | Calcium activity interpolated to behavior-frame timestamps. |
| `neuron_name_<animal>` | `n_neurons` | Cortical area label/name for each neuron. |
| `neuron_center_<animal>` | `n_neurons x 2` | Neuron center coordinates from the calcium field of view. |
| `mouse_center_<animal>` | `2 x 7601` | Mouse mask centroid in behavior-video pixel coordinates, stored as `[x; y]`. |

Animals included in `data_aligned.mat`:

| Animal | Calcium shape | Neuron center shape | Mouse center shape |
| --- | ---: | ---: | ---: |
| `03_new` | `5148 x 7601` | `5148 x 2` | `2 x 7601` |
| `05_new` | `4609 x 7601` | `4609 x 2` | `2 x 7601` |
| `06_new` | `4775 x 7601` | `4775 x 2` | `2 x 7601` |
| `07` | `5129 x 7601` | `5129 x 2` | `2 x 7601` |
| `80` | `1736 x 7601` | `1736 x 2` | `2 x 7601` |

The first aligned timestamp is `04-Jan-25/16-27-06-479130`; the last aligned
timestamp is `04-Jan-25/16-37-41-576910`.

## `segment_mask.pickle`

`segment_mask.pickle` is a gzip-compressed Python pickle. It contains a list
with one entry per video frame. Each non-empty frame entry is a dictionary:

```python
{
    sam2_object_id: packed_binary_mask
}
```

The masks were stored with `numpy.packbits`. To restore a mask:

```python
import gzip
import pickle
import numpy as np

mask_path = "segment_mask.pickle"

with gzip.open(mask_path, "rb") as f:
    video_segments = pickle.load(f)

frame_index = 2918
obj_id = 1

packed_mask = video_segments[frame_index][obj_id]
mask = np.unpackbits(packed_mask).astype(np.int8).reshape((944, 968))
```

SAM2 object id mapping for this release:

| SAM2 object id | Animal |
| ---: | --- |
| `1` | `03_new` |
| `2` | `05_new` |
| `3` | `80` |
| `4` | `06_new` |
| `5` | `07` |

The first non-empty mask frame is frame `2916`.

## Minimal loading examples

Load the aligned MATLAB file in Python:

```python
import scipy.io as sio

mat_path = r"data_aligned.mat"
data = sio.loadmat(mat_path)

start_frame = int(data["start_frame"][0, 0])
end_frame = int(data["end_frame"][0, 0])
calcium_03 = data["calcium_03_new"]       # n_neurons x aligned_frames
mouse_center_03 = data["mouse_center_03_new"]  # 2 x aligned_frames, [x; y]
```

Load the aligned MATLAB file in MATLAB:

```matlab
data = load('data_aligned.mat');

start_frame = data.start_frame;
end_frame = data.end_frame;
calcium_03 = data.calcium_03_new;
mouse_center_03 = data.mouse_center_03_new;
```

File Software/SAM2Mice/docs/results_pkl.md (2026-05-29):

# Saving and Loading Segmentation Results

After every `run()` / `run_bootstrapping()` call, SAM2Mice automatically saves results to the `save_dir` you specified:

```
save_dir/
├── segment_masks.pickle   # gzip-compressed mask data (main output)
├── segmented_video.mp4    # visualised overlay video
└── frames/ (or saved_masks/)   # per-frame overlay images
```

The `.pickle` file stores all per-frame, per-object binary masks in a memory-efficient packbits format. It must be loaded together with the **mask shape** `(H, W)` that is returned by `run()`.

---

## Saving

`save_video_segments` is called automatically inside `run()` and `run_bootstrapping()`. The return value of those calls includes the shape tuple needed for loading.

```python
video_segments, output_video_path = predictor.run(
    frames_dir=frames_dir,
    prompt_source="manual",
    prompt_type="point",
    save_dir="results/base",
    fps=20,
)
# shape is stored automatically; retrieve it from the manager if needed:
shape = predictor.segment_manager._mask_shape   # (H, W)
```

If you need to save manually (e.g. after post-processing):

```python
shape = predictor.segment_manager.save_video_segments("results/base/segment_masks.pickle")
print(f"Saved. Mask shape: {shape}")   # e.g. (1080, 1920)
```

---

## Loading

Use `load_segments` on any `VideoSegmentationInference` or `BootstrappingVideoSegmentationInference` instance. You must supply the `(H, W)` shape that was returned when the file was saved.

```python
from SAM2_Mice.segmentation import VideoSegmentationInference

predictor = VideoSegmentationInference(
    model_cfg="configs/sam2.1/sam2.1_hiera_b+.yaml",
    checkpoint_path="checkpoints/SAM2_Mice_base_plus.pt",
)

import os
frames_dir = "data/frames"
frame_names = sorted(f for f in os.listdir(frames_dir) if f.endswith(".jpg"))
frame_paths = [os.path.join(frames_dir, n) for n in frame_names]

shape = (1080, 1920)   # must match the shape returned when saving

segments = predictor.load_segments(
    pickle_path="results/base/segment_masks.pickle",
    shape=shape,
    frame_paths=frame_paths,   # optional; required for re-rendering
)
```

`segments` is a list aligned with `frame_paths`. Each element is either `None` (no detection on that frame) or a dict mapping object ID → mask array of shape `(1, H, W)` with `int8` values (0 or 1).

```python
frame_idx = 0
seg = segments[frame_idx]   # None  OR  {obj_id: np.ndarray (1,H,W)}

if seg is not None:
    for obj_id, mask in seg.items():
        print(f"frame {frame_idx}, object {obj_id}: mask sum = {mask.sum()}")
```

---

## Re-rendering after loading

Once frames are loaded via `load_segments`, you can re-generate the overlay video without re-running inference:

```python
predictor.segment_manager.generate_masked_video_and_image(
    output_video_path="results/base/rerendered_video.mp4",
    fps=20,
    temp_folder="results/base/rerendered_frames",
    save_masks=True,   # set False to delete per-frame images after video is written
)
```

Or use the `supervision`-based annotator which also draws bounding boxes and labels:

```python
predictor.segment_manager.generate_masked_video_supervision(
    output_video_path="results/base/annotated_video.mp4",
    fps=20,
    mask_save_folder="results/base/annotated_frames",
)
```

---

## Direct access to decompressed masks

If you want to iterate over all frames without loading the full list into memory at once, use the internal method directly:

```python
import gzip, pickle
import numpy as np

shape = (1080, 1920)  # (H, W)

with gzip.open("results/base/segment_masks.pickle", "rb") as f:
    packed_segments = pickle.load(f)  # list of None | {obj_id: uint8 packbits array}

for frame_idx, packed in enumerate(packed_segments):
    if packed is None:
        continue
    for obj_id, bits in packed.items():
        mask = np.unpackbits(bits)[: shape[0] * shape[1]].reshape(1, *shape).astype(np.int8)
        # mask shape: (1, H, W), values 0 or 1
```

> **Note:** The packbits format pads the last byte if `H * W` is not a multiple of 8. Always slice with `[: H * W]` before reshaping.

---

## Bootstrapping results

`run_bootstrapping()` writes a single merged `segment_masks.pickle` covering all batches, at the same path and in the same format as the basic workflow. Loading is identical — use the same `load_segments` call shown above.

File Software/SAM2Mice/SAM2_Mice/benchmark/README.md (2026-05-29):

## Benchmark with DeepLabCut and SuperAnimal

We benchmarked SAM2Mice against [SuperAnimal](https://www.nature.com/articles/s41467-024-48792-2) and [DeepLabCut](https://www.nature.com/articles/s41592-022-01443-0) using the MOT metrics computed with *pymotmetrics*. For evaluation, we converted SAM2Mice's segmentation masks and DeepLabCut's keypoints into bounding boxes.

### DeepLabCut Environment
For DeepLabCut we used the TensorFlow-based 2.3.10 release. We provide the output files for evaluation data in the link below.
If you want to run with yourself, install with:

```bash
pip install 'deeplabcut[gui,tf]==2.3.10'
```

If you only need inference (no GUI), you can omit `gui`.

### Additional Python Dependencies
Besides project requirements, the benchmarking notebook/code uses:

```bash
pip install motmetrics tables h5py matplotlib numpy pillow
```

`motmetrics` is sometimes imported internally via `pymotmetrics`; installing `motmetrics` covers it.

You could download the validation data from [google drive](https://drive.google.com/drive/folders/122uAEX-X8AzZk4sBm5zemSk0FWKehDhZ?usp=drive_link). The data folder will be as follows:

```bash
DATA_ROOT/
├── openfield_five_mouse/           # The raw frames of the video
├── ground_truth_bb_labels/         # Bounding box annotated, stored as labelimg format
├── SuperAnimal_output/             # Output files inferenced by SuperAnimal
├── DLC_trained_output/             # Output files inferenced by DeepLabCut
└── openfield_five_mouse_seg/       # Segment masks saved in a pickle file
```

### Overview of the Benchmarking Steps
1. Convert SAM2Mice segmentation masks to YOLO-format bounding boxes (using `mask_to_box_labelimg.py`).
2. (Optional) Visualize converted labels over the raw frames to sanity‑check quality.
3. Compute MOT metrics (MOTA, IDF1, IDs, FN, etc.) for SuperAnimal, DeepLabCut, and SAM2Mice via `compute_metrics.py`.
4. Plot aggregated metrics for comparison.

You can follow the interactive workflow in the notebook [bench_mark.ipynb](bench_mark.ipynb).

## Tracking Metrics Evaluation

This repo uses py-motmetrics to compute standard MOT metrics, including MOTA, MOTP, IDF1, ID switches, FP, and FN.

Supported inputs:

- Keypoints HDF5: DLC-style multi-index DataFrame with `x`, `y`, and `likelihood` coordinates per individual. We reconstruct per-individual boxes with a margin and average likelihood as confidence.
- YOLO label directories: per-frame `.txt` files such as `00000.txt`, `00001.txt`, and `classes.txt`. Each label line is `class_id cx cy w h [optional_conf]`. Boxes are normalized to `[0, 1]` and converted to pixels using the provided image width and height.

### Convert SAM2Mice Masks to YOLO Boxes

If you have packed binary masks per frame, convert them into YOLO boxes:

```bash
python -m SAM2_Mice.benchmark.mask_to_box_labelimg convert \
  --pickle /path/to/processed_segments.pkl \
  --out /path/to/SAM2_labels \
  --height 1024 \
  --width 1224 \
  --format yolo \
  --min-area 900
```

Optionally visualize boxes over images:

```bash
python -m SAM2_Mice.benchmark.mask_to_box_labelimg vis \
  --images /path/to/images \
  --labels /path/to/SAM2_labels \
  --out /path/to/vis_out \
  --format yolo
```

### Evaluate Keypoint Predictions

Use `compute_metrics.py` to evaluate ground-truth YOLO boxes against predicted HDF5 keypoints. The keypoints are converted to boxes internally.

```python
from SAM2_Mice.benchmark.compute_metrics import compute_mot_metrics

results, summary = compute_mot_metrics(
    gt_path="/path/to/gt_keypoints.h5",
    pred_path="/path/to/pred_keypoints.h5",
    tracker_type="bbox",
    margin=5.0,
    match_in_first_frame=False,
    save_path="metrics_keypoints.pkl",
)
print(summary)
```

### Evaluate YOLO Box Predictions

Use `compute_metrics.py` to evaluate ground-truth YOLO boxes against predicted YOLO boxes from masks.

```python
from SAM2_Mice.benchmark.compute_metrics import compute_mot_metrics

results, summary = compute_mot_metrics(
    gt_path="/path/to/GT_labels_yolo",
    pred_path="/path/to/SAM2_labels",
    tracker_type="bbox",
    yolo_img_shape=(1224, 1024),
    match_in_first_frame=False,
    save_path="metrics_sam2.pkl",
)
print(summary)
```

## Results

We benchmarked SAM2Mice with SuperAnimal and DeepLabCut on 3-mouse and 5-mouse videos. Compared with keypoint-based tracking methods, SAM2Mice provides richer spatial descriptions, greater noise robustness, and resistance to long-duration drift.

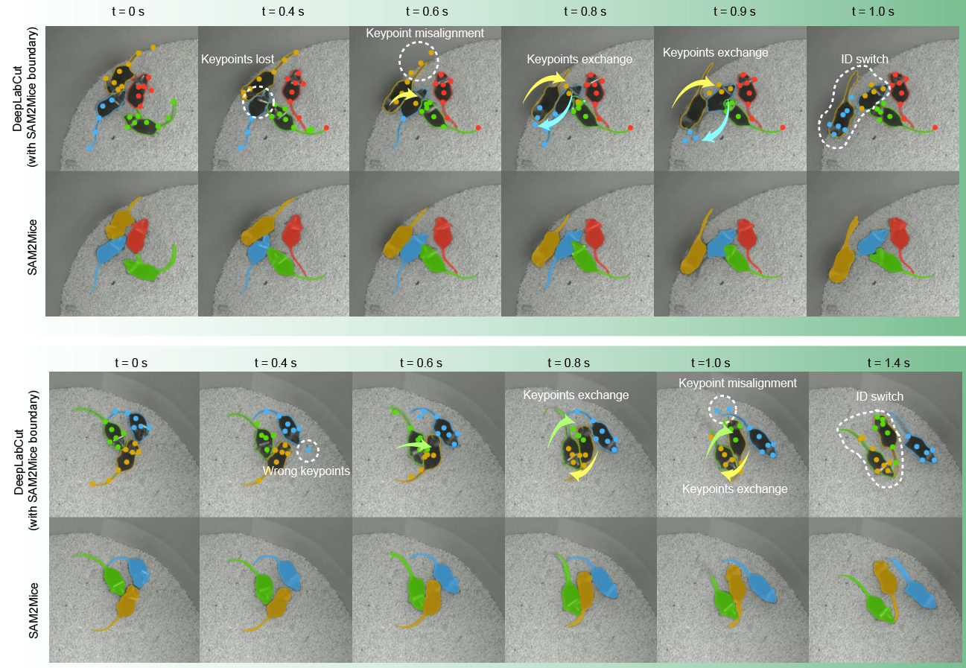
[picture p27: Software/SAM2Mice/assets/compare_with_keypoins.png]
Comparison with keypoints


### 3 Mice Open Field

| Method | MOTA (up) | FN (down) | Recall (up) | IDF1 (up) | ID switches (down) | FM (down) |
| --- | --- | --- | --- | --- | --- | --- |
| SuperAnimal | 0.478 +/- 0.040 | 276.3 +/- 95.8 | 0.724 +/- 0.095 | 0.395 +/- 0.024 | 234.7 +/- 56.9 | 54.7 +/- 10.5 |
| DeepLabCut | 0.881 +/- 0.055 | 60.0 +/- 27.7 | 0.940 +/- 0.028 | 0.940 +/- 0.027 | 0.0 +/- 0.0 | 20.0 +/- 2.9 |
| **SAM2Mice** | **0.979 +/- 0.029** | **10.3 +/- 14.6** | **0.990 +/- 0.015** | **0.990 +/- 0.015** | **0.0 +/- 0.0** | **2.3 +/- 3.3** |

### 5 Mice Open Field

| Method | MOTA (up) | FN (down) | Recall (up) | IDF1 (up) | ID switches (down) | FM (down) |
| --- | --- | --- | --- | --- | --- | --- |
| SuperAnimal | 0.179 +/- 0.016 | 863.0 +/- 11.3 | 0.482 +/- 0.008 | 0.183 +/- 0.009 | 445.0 +/- 31.4 | 218.0 +/- 26.1 |
| DeepLabCut | 0.703 +/- 0.042 | 280.0 +/- 56.4 | 0.832 +/- 0.034 | 0.757 +/- 0.109 | 4.3 +/- 4.8 | 86.3 +/- 1.9 |
| **SAM2Mice** | **0.958 +/- 0.026** | **34.7 +/- 21.5** | **0.979 +/- 0.013** | **0.979 +/- 0.013** | **0.0 +/- 0.0** | **12.3 +/- 4.7** |

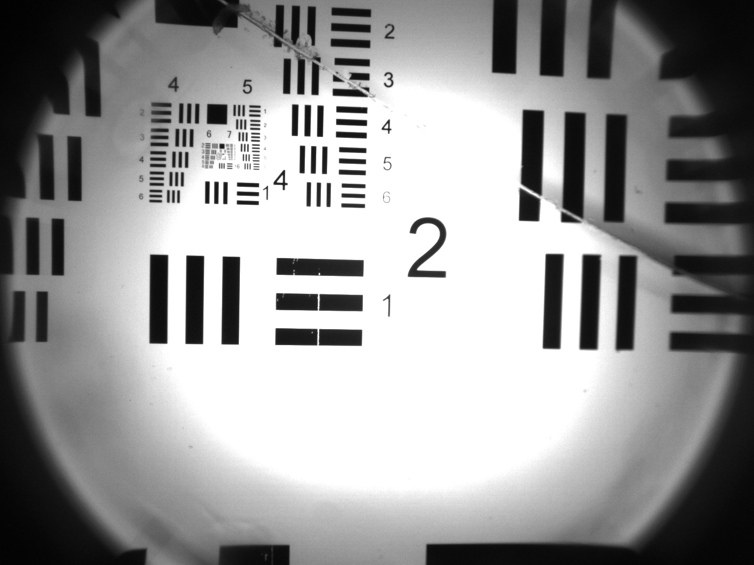
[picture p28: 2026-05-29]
Data_release/optical_characteristic/USAF-3.jpg

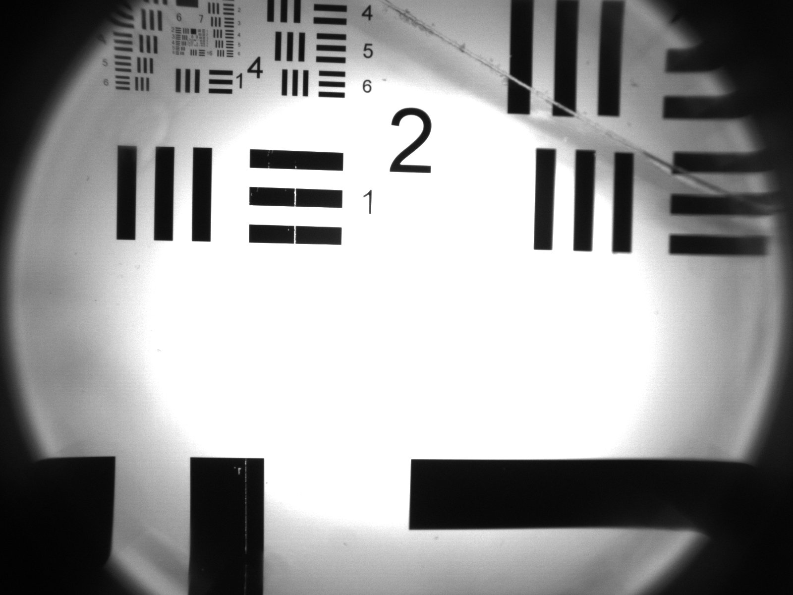
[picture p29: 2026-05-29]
Data_release/optical_characteristic/USAF-4.jpg

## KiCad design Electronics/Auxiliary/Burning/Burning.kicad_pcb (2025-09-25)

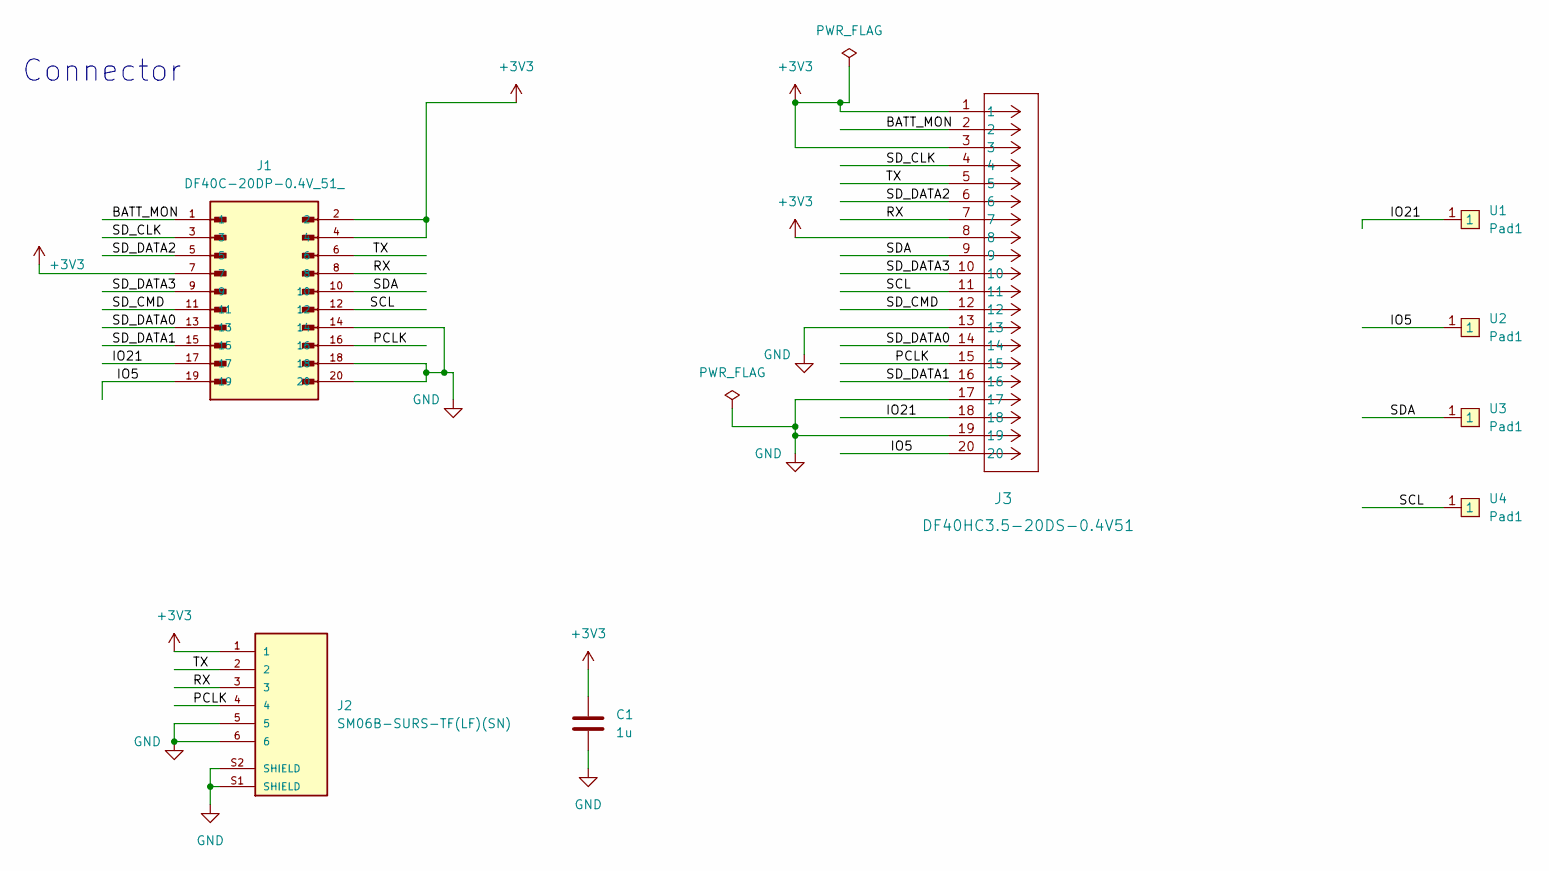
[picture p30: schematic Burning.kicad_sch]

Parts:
C1: 1u; C_0402_Metric
J1: DF40C-20DP-0.4V_51_; HRS_DF40C-20DP-0.4V_51_; PARTREV 02/2020
J2: SM06B-SURS-TF(LF)(SN); JST_SM06B-SURS-TF(LF)(SN); PARTREV N/A
J3: DF40HC3.5-20DS-0.4V51; CONN20_DF40HC_HIR
U1, U2, U3, U4: Pad1; Rec_Pad_1

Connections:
+3V3: C1.1, J1.2, J1.4, J1.7, J2.1, J3.1, J3.3, J3.8
/BATT_MON: J1.1, J3.2
/IO5: J1.19, J3.20, U2.1
/IO21: J1.17, J3.18, U1.1
/PCLK: J1.16, J2.4, J3.15
/RX: J1.8, J2.3, J3.7
/SCL: J1.12, J3.11, U4.1
/SDA: J1.10, J3.9, U3.1
/SD_CLK: J1.3, J3.4
/SD_CMD: J1.11, J3.12
/SD_DATA0: J1.13, J3.14
/SD_DATA1: J1.15, J3.16
/SD_DATA2: J1.5, J3.6
/SD_DATA3: J1.9, J3.10
/TX: J1.6, J2.2, J3.5
GND: C1.2, J1.14, J1.18, J1.20, J2.5, J2.6, J2.S1 (SHIELD), J2.S2 (SHIELD), J3.13, J3.17, J3.19

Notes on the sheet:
Connector

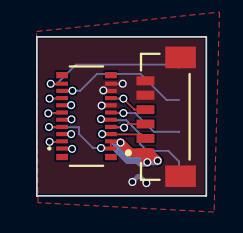
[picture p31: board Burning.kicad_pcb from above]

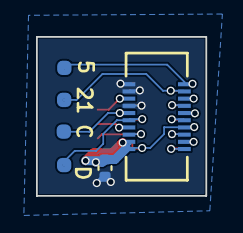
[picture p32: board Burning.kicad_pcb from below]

Board: 2 copper layers, 9.4 x 8.8 mm, 8 parts (6 on the bottom side), 16 nets.

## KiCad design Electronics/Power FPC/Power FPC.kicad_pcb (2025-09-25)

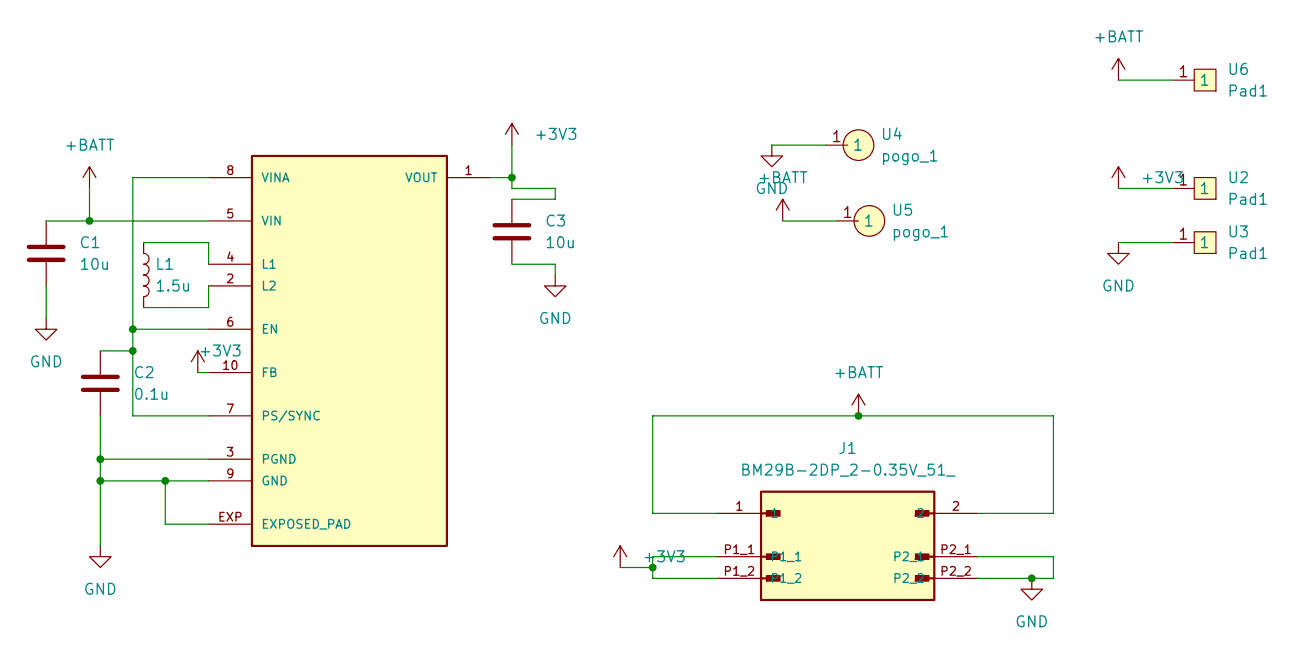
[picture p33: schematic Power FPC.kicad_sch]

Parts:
C1, C3: 10u; C_0603_Metric
C2: 0.1u; C_0402_Metric
J1: BM29B-2DP_2-0.35V_51_; BM29B-2DP_2-0.35V_51__HRS_BM29B-2DP_2-0.35V_51_; PARTREV 20210716
L1: 1.5u; ASIC-0805F
U1: TPS63031; TPS63031-10SON
U2, U3, U6: Pad1; Rec_Pad_1
U4, U5: pogo_1

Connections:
+3V3: C3.1, J1.P1_1, J1.P1_2, U1.1 (VOUT), U1.10 (FB), U2.1
+BATT: C1.1, J1.1, J1.2, U1.5 (VIN), U5.1, U6.1
GND: C1.2, C2.2, C3.2, J1.P2_1, J1.P2_2, U1.3 (PGND), U1.9 (GND), U1.EXP (EXPOSED_PAD), U3.1, U4.1
unnamed: C2.1, U1.6 (EN), U1.7 (PS/SYNC), U1.8 (VINA)
unnamed: L1.1, U1.4 (L1)
unnamed: L1.2, U1.2 (L2)

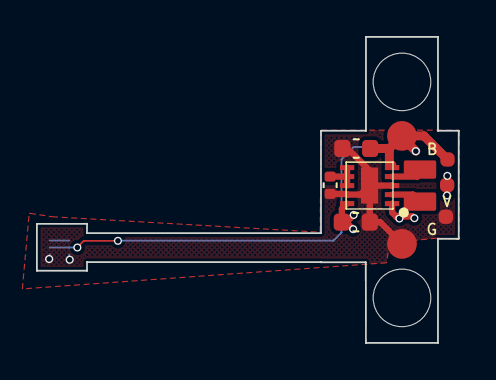
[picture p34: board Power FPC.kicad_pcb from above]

Board: 2 copper layers, 23.4 x 17.0 mm, 11 parts (1 on the bottom side), 6 nets.

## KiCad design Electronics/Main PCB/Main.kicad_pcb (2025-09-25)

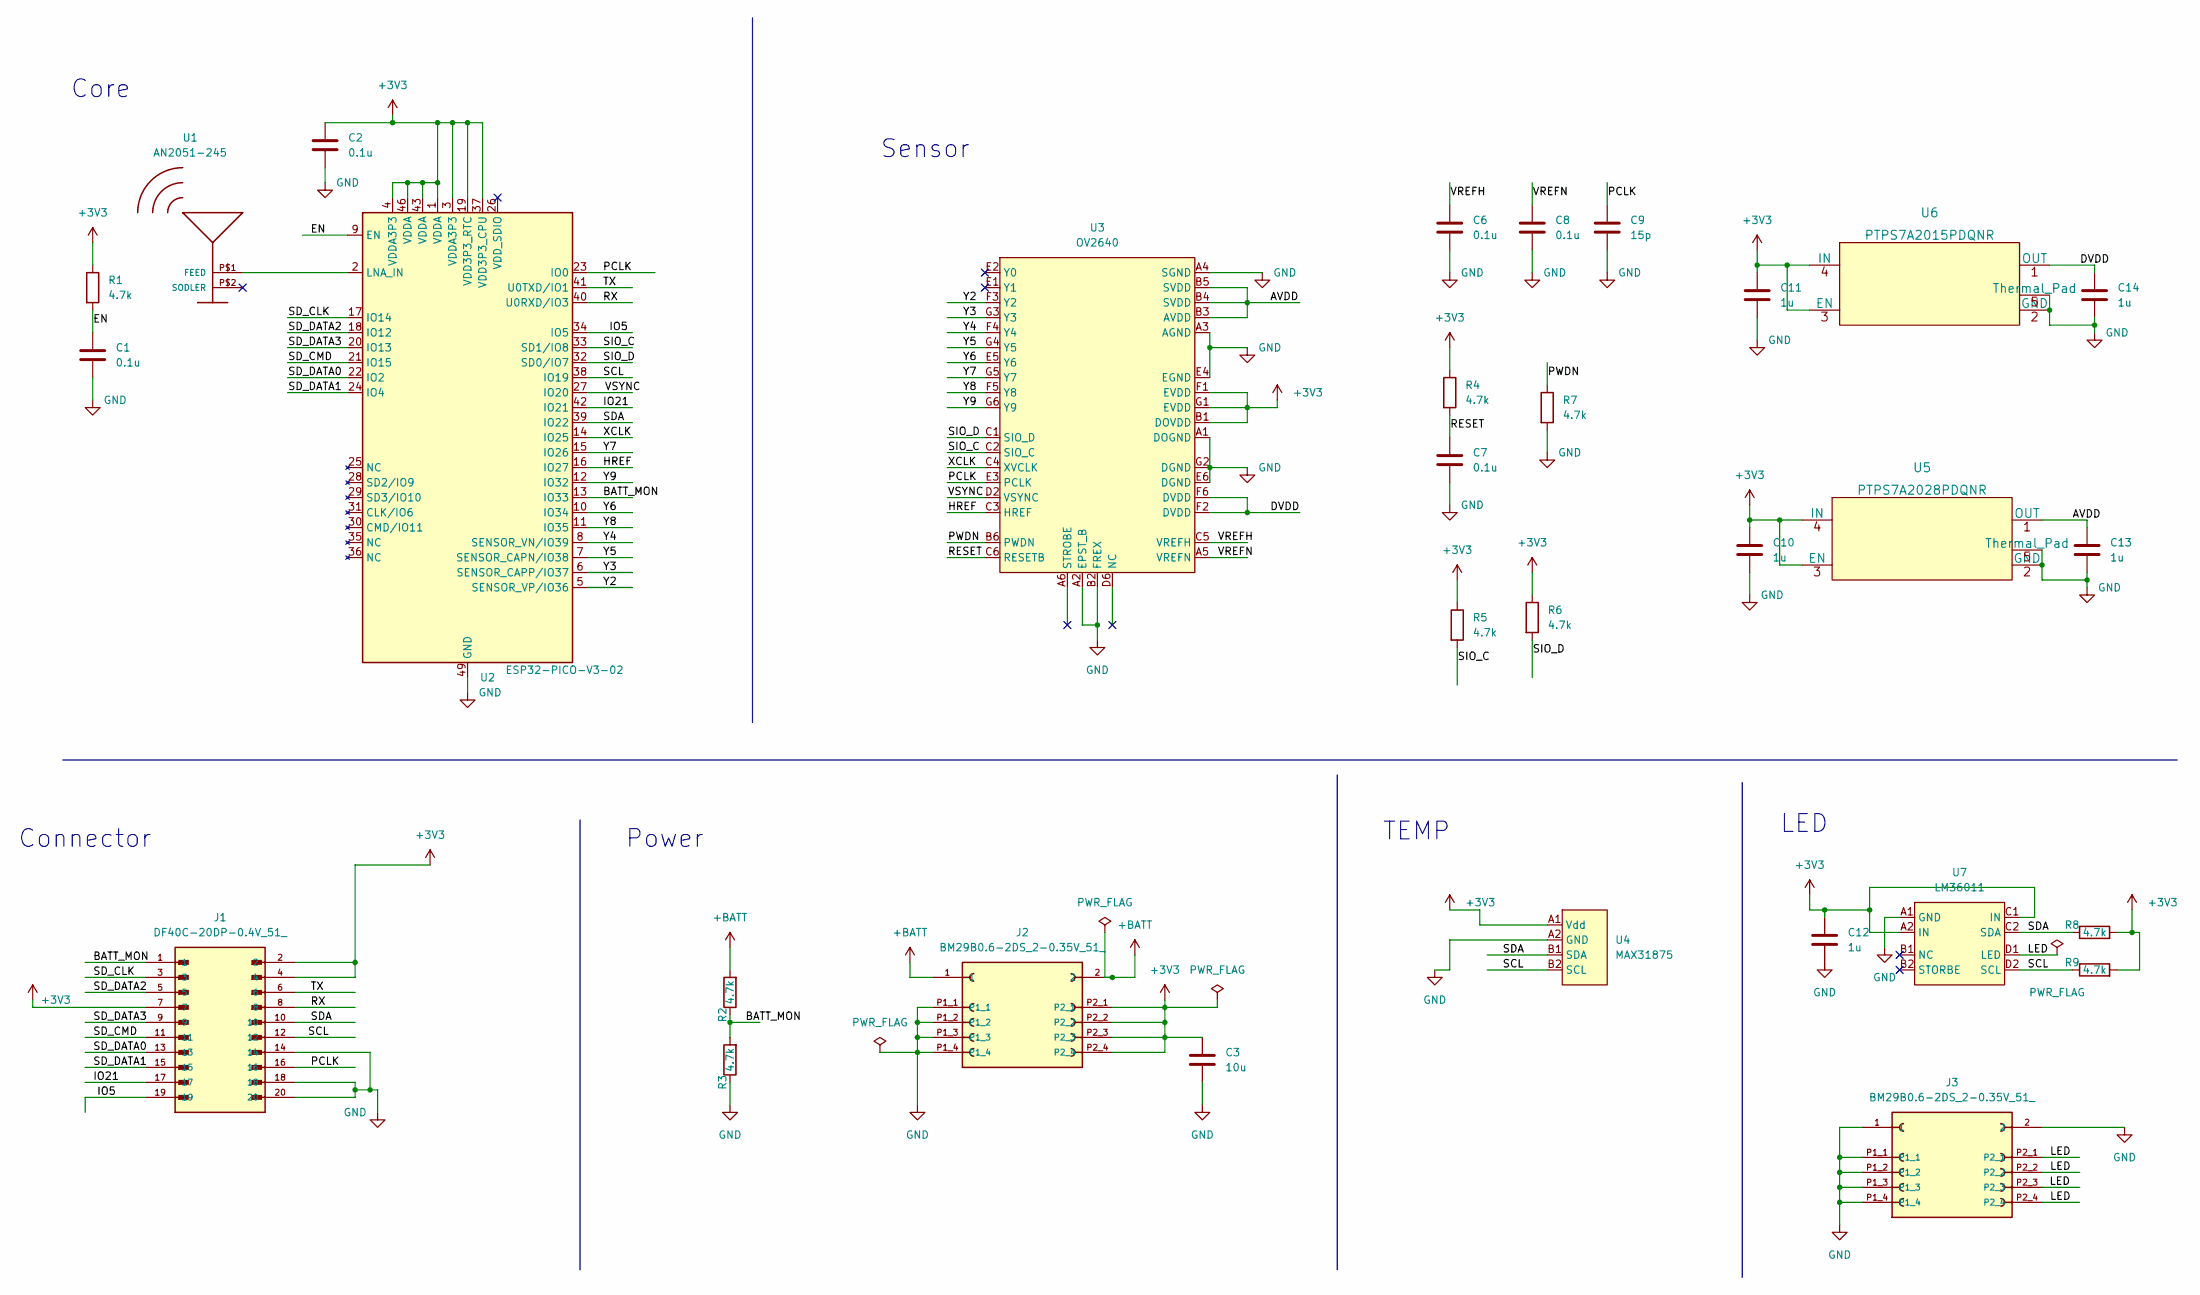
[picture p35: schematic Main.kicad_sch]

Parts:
C1, C2, C6, C7, C8: 0.1u; C_0201_Metric
C3: 10u; C_0603_Metric
C9: 15p; C_0201_Metric
C10, C11, C12, C13, C14: 1u; C_0201_Metric
J1: DF40C-20DP-0.4V_51_; HRS_DF40C-20DP-0.4V_51_; PARTREV 02/2020
J2, J3: BM29B0.6-2DS_2-0.35V_51_; BM29B0.6-2DS_2-0.35V_51__HRS_BM29B0.6-2DS_2-0.35V_51_; PARTREV 20210414
R1, R2, R3, R4, R5, R6, R7, R8, R9: 4.7k; R_0201_Metric
U1: AN2051-245; AN2051
U2: ESP32-PICO-V3-02; Pico-QFN-48
U3: OV2640; OV2640_BGA38
U4: MAX31875; BGA4N40P2X2_83X83X37N
U5: PTPS7A2028PDQNR; PTPS7A20185PDQNR
U6: PTPS7A2015PDQNR; PTPS7A20185PDQNR
U7: LM36011; LM36011_BGA24

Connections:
+3V3: C2.1, C3.1, C10.1, C11.1, C12.1, J1.2, J1.4, J1.7, J2.P2_1, J2.P2_2, J2.P2_3, J2.P2_4, R1.1, R4.1, R5.1, R6.1, R8.2, R9.2, U2.1 (VDDA), U2.3 (VDDA3P3), U2.4 (VDDA3P3), U2.19 (VDD3P3_RTC), U2.37 (VDD3P3_CPU), U2.43 (VDDA), U2.46 (VDDA), U3.B1 (DOVDD), U3.F1 (EVDD), U3.G1 (EVDD), U4.A1 (Vdd), U5.3 (EN), U5.4 (IN), U6.3 (EN), U6.4 (IN), U7.A2 (IN), U7.C1 (IN)
+BATT: J2.1, J2.2, R2.2
/AVDD: C13.1, U3.B3 (AVDD), U3.B4 (SVDD), U3.B5 (SVDD), U5.1 (OUT)
/BATT_MON: J1.1, R2.1, R3.2, U2.13 (IO33)
/DVDD: C14.1, U3.F2 (DVDD), U3.F6 (DVDD), U6.1 (OUT)
/EN: C1.1, R1.2, U2.9 (EN)
/HREF: U2.16 (IO27), U3.C3 (HREF)
/IO5: J1.19, U2.34 (IO5)
/IO21: J1.17, U2.42 (IO21)
/LED: J3.P2_1, J3.P2_2, J3.P2_3, J3.P2_4, U7.D1 (LED)
/PCLK: C9.1, J1.16, U2.23 (IO0), U3.E3 (PCLK)
/PWDN: R7.1, U3.B6 (PWDN)
/RESET: C7.1, R4.2, U3.C6 (RESETB)
/RX: J1.8, U2.40 (U0RXD/IO3)
/SCL: J1.12, R9.1, U2.38 (IO19), U4.B2 (SCL), U7.D2 (SCL)
/SDA: J1.10, R8.1, U2.39 (IO22), U4.B1 (SDA), U7.C2 (SDA)
/SD_CLK: J1.3, U2.17 (IO14)
/SD_CMD: J1.11, U2.21 (IO15)
/SD_DATA0: J1.13, U2.22 (IO2)
/SD_DATA1: J1.15, U2.24 (IO4)
/SD_DATA2: J1.5, U2.18 (IO12)
/SD_DATA3: J1.9, U2.20 (IO13)
/SIO_C: R5.2, U2.33 (SD1/IO8), U3.C2 (SIO_C)
/SIO_D: R6.2, U2.32 (SD0/IO7), U3.C1 (SIO_D)
/TX: J1.6, U2.41 (U0TXD/IO1)
/VREFH: C6.1, U3.C5 (VREFH)
/VREFN: C8.1, U3.A5 (VREFN)
/VSYNC: U2.27 (IO20), U3.D2 (VSYNC)
/XCLK: U2.14 (IO25), U3.C4 (XVCLK)
/Y2: U2.5 (SENSOR_VP/IO36), U3.F3 (Y2)
/Y3: U2.6 (SENSOR_CAPP/IO37), U3.G3 (Y3)
/Y4: U2.8 (SENSOR_VN/IO39), U3.F4 (Y4)
/Y5: U2.7 (SENSOR_CAPN/IO38), U3.G4 (Y5)
/Y6: U2.10 (IO34), U3.E5 (Y6)
/Y7: U2.15 (IO26), U3.G5 (Y7)
/Y8: U2.11 (IO35), U3.F5 (Y8)
/Y9: U2.12 (IO32), U3.G6 (Y9)
GND: C1.2, C2.2, C3.2, C6.2, C7.2, C8.2, C9.2, C10.2, C11.2, C12.2, C13.2, C14.2, J1.14, J1.18, J1.20, J2.P1_1, J2.P1_2, J2.P1_3, J2.P1_4, J3.1, J3.2, J3.P1_1, J3.P1_2, J3.P1_3, J3.P1_4, R3.1, R7.2, U2.49 (GND), U3.A1 (DOGND), U3.A2 (EPST_B), U3.A3 (AGND), U3.A4 (SGND), U3.B2 (FREX), U3.E4 (EGND), U3.E6 (DGND), U3.G2 (DGND), U4.A2 (GND), U5.2 (GND), U5.5 (Thermal_Pad), U6.2 (GND), U6.5 (Thermal_Pad), U7.A1 (GND)
unnamed: U1.P$1 (FEED), U2.2 (LNA_IN)

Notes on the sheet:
Sensor
Power
TEMP
Connector
LED
Core

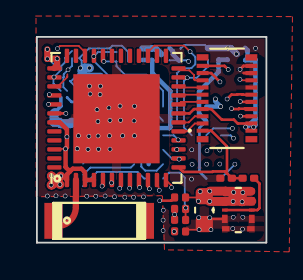
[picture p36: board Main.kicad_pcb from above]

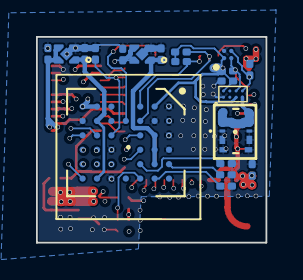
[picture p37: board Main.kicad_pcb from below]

Board: 6 copper layers, 12.8 x 11.4 mm, 31 parts (20 on the bottom side), 39 nets.

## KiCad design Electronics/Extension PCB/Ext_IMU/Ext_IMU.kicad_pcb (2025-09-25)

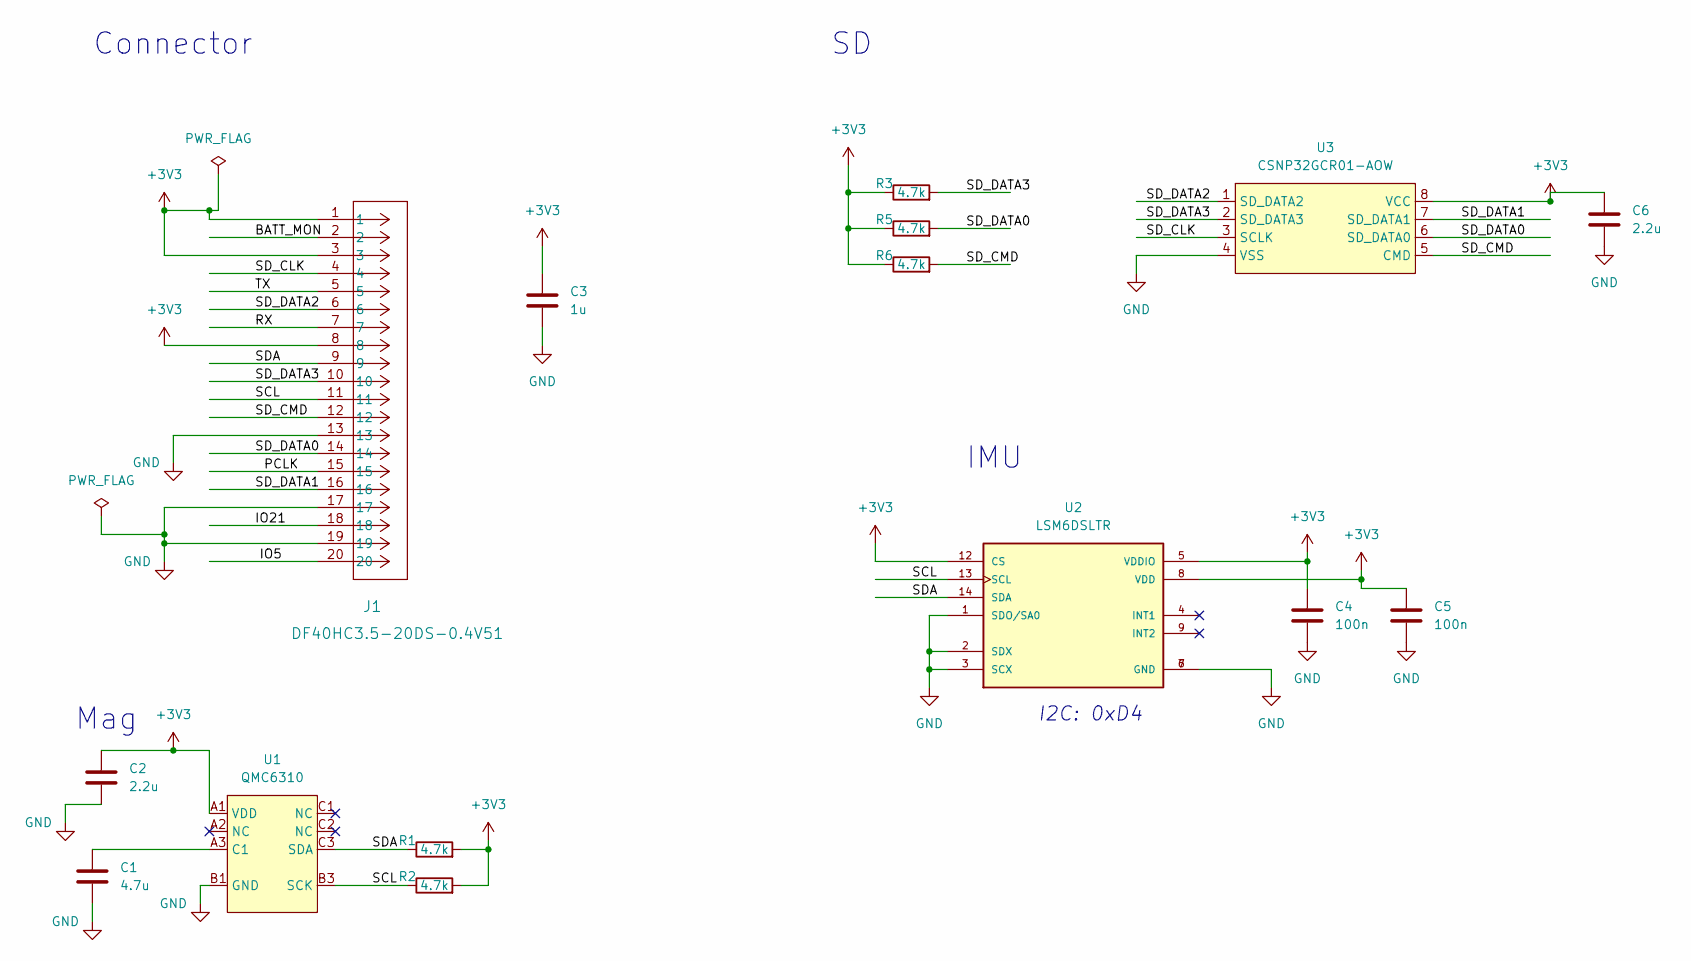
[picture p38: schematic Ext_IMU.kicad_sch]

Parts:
C1: 4.7u; C_0201_Metric
C2, C6: 2.2u; C_0201_Metric
C3: 1u; C_0402_Metric
C4, C5: 100n; C_0201_Metric
J1: DF40HC3.5-20DS-0.4V51; CONN20_DF40HC_HIR
R1, R2, R3, R5, R6: 4.7k; R_0201_Metric
U1: QMC6310
U2: LSM6DSLTR; LSM6DSLTR_PQFN50P300X250X86-14N; PARTREV 7
U3: CSNP32GCR01-AOW; SD_NAND_32

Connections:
+3V3: C2.1, C3.1, C4.1, C5.1, C6.1, J1.1, J1.3, J1.8, R1.2, R2.2, R3.1, R5.1, R6.1, U1.A1 (VDD), U2.5 (VDDIO), U2.8 (VDD), U2.12 (CS), U3.8 (VCC)
/BATT_MON: J1.2
/IO5: J1.20
/IO21: J1.18
/PCLK: J1.15
/RX: J1.7
/SCL: J1.11, R2.1, U1.B3 (SCK), U2.13 (SCL)
/SDA: J1.9, R1.1, U1.C3 (SDA), U2.14 (SDA)
/SD_CLK: J1.4, U3.3 (SCLK)
/SD_CMD: J1.12, R6.2, U3.5 (CMD)
/SD_DATA0: J1.14, R5.2, U3.6 (SD_DATA0)
/SD_DATA1: J1.16, U3.7 (SD_DATA1)
/SD_DATA2: J1.6, U3.1 (SD_DATA2)
/SD_DATA3: J1.10, R3.2, U3.2 (SD_DATA3)
/TX: J1.5
GND: C1.2, C2.2, C3.2, C4.2, C5.2, C6.2, J1.13, J1.17, J1.19, U1.B1 (GND), U2.1 (SDO/SA0), U2.2 (SDX), U2.3 (SCX), U2.6 (GND), U2.7 (GND), U3.4 (VSS)
unnamed: C1.1, U1.A3 (C1)

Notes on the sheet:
I2C: 0xD4
IMU
Mag
Connector

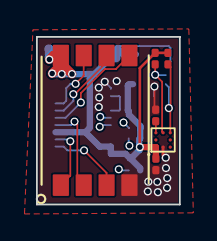
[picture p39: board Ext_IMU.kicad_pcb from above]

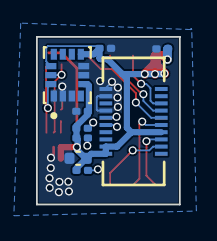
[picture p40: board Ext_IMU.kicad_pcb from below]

Board: 4 copper layers, 7.9 x 9.3 mm, 15 parts (9 on the bottom side), 11 nets.

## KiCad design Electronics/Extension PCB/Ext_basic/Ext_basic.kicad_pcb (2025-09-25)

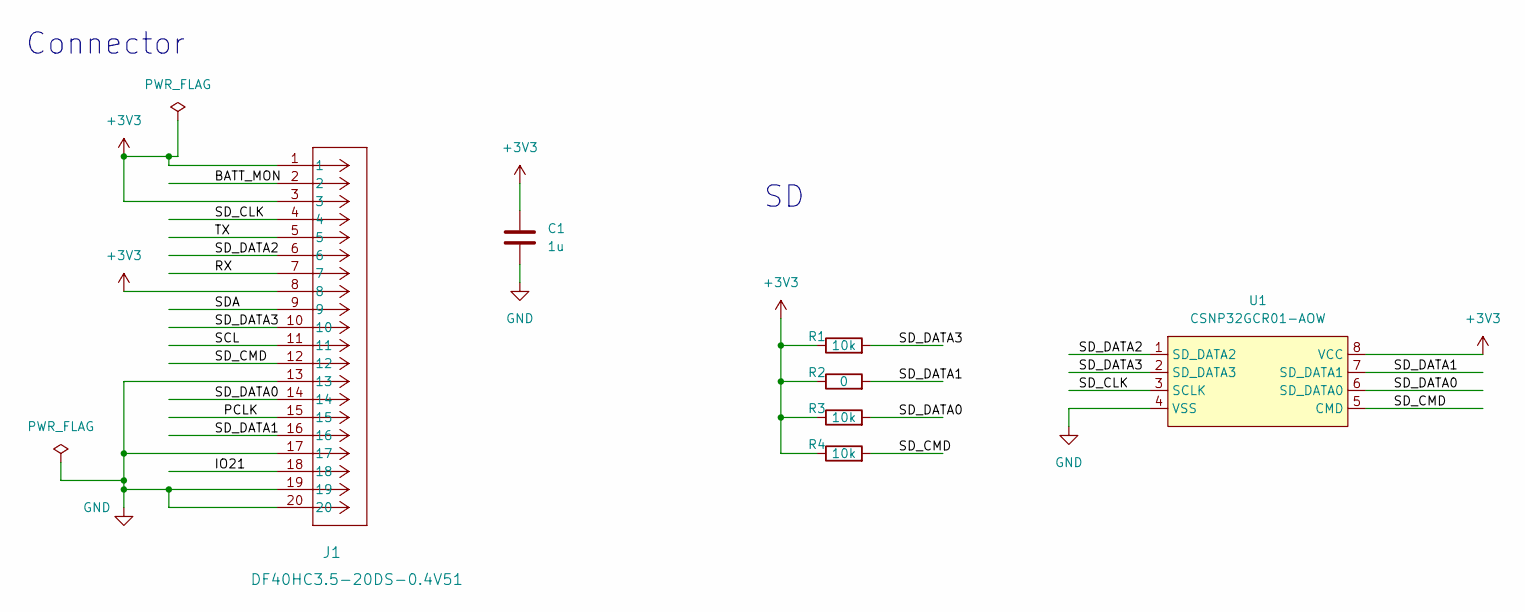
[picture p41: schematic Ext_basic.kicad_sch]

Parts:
C1: 1u; C_0402_Metric
J1: DF40HC3.5-20DS-0.4V51; CONN20_DF40HC_HIR
R1, R3, R4: 10k; R_0201_Metric
R2: 0; R_0201_Metric
U1: CSNP32GCR01-AOW; SD_NAND_32

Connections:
+3V3: C1.1, J1.1, J1.3, J1.8, R1.1, R2.1, R3.1, R4.1, U1.8 (VCC)
/BATT_MON: J1.2
/IO21: J1.18
/PCLK: J1.15
/RX: J1.7
/SCL: J1.11
/SDA: J1.9
/SD_CLK: J1.4, U1.3 (SCLK)
/SD_CMD: J1.12, R4.2, U1.5 (CMD)
/SD_DATA0: J1.14, R3.2, U1.6 (SD_DATA0)
/SD_DATA1: J1.16, R2.2, U1.7 (SD_DATA1)
/SD_DATA2: J1.6, U1.1 (SD_DATA2)
/SD_DATA3: J1.10, R1.2, U1.2 (SD_DATA3)
/TX: J1.5
GND: C1.2, J1.13, J1.17, J1.19, J1.20, U1.4 (VSS)

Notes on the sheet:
Connector



Board: 2 copper layers, 6.5 x 9.0 mm, 7 parts (6 on the bottom side), 8 nets.

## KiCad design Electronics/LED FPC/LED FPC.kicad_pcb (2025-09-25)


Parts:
J1: BM29B-2DP_2-0.35V_51_; BM29B-2DP_2-0.35V_51__HRS_BM29B-2DP_2-0.35V_51_; PARTREV 20210716
U1, U2, U3, U4: LXZ1-PB01
U5, U6: Pad1; Rec_Pad_1

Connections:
GND: J1.1, J1.2, J1.P2_1, J1.P2_2, U1.1 (N), U2.1 (N), U3.1 (N), U4.1 (N), U6.1
VCC: J1.P1_1, J1.P1_2, U1.2, U2.2, U3.2, U4.2, U5.1



Board: 2 copper layers, 27.0 x 7.6 mm, 7 parts (2 on the bottom side), 2 nets.

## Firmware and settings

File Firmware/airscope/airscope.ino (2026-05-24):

/*********
  Airscope v2 firmware - NO-BLE variant.

  Same as airscope_v2 except BLE is stripped. Used to isolate whether the
  MJPEG stream instability seen on Princeton's Wi-Fi comes from BLE
  (compile-time linkage of the BT controller and/or its deinit leaving the
  radio in a degraded coexistence state) or from the ESP32 core 2.0.17
  itself / network. Keep the same FQBN + core so BLE-presence is the only
  variable.

  Board: AI Thinker ESP32-CAM (PICO_11 pin map in periphery.h).
  Dependencies: ArduinoJson (Library Manager).
*********/

#include "capture.h"
#include "periphery.h"
#include "config.h"

#include "soc/soc.h"
#include "soc/rtc_cntl_reg.h"
#include "driver/rtc_io.h"
#include <WiFi.h>

void startCameraServer();
int  capture_time = 5;          // overridden from config in setup()
bool start_capture = false;

static void apply_camera_defaults_from_config();

void setup() {
    WRITE_PERI_REG(RTC_CNTL_BROWN_OUT_REG, 0);
    Serial.begin(115200);

    // SD must come up first so config_load_from_sd() has somewhere to read.
    init_writer();

    // Load defaults, then layer SD config on top (if available).
    config_load_defaults();
    config_load_from_sd();
    capture_time = g_config.default_capture_time;

    // Write /log.txt at SD root so the MAC address is easy to find for pairing.
    write_boot_log();

    init_camera();
    apply_camera_defaults_from_config();

    initI2C();
    get_initial_batt_value();

    init_wifi(g_config.wifi_ssid.c_str(), g_config.wifi_password.c_str());

    start_capture_service();   // RTOS capture loop
    startCameraServer();       // HTTP + MJPEG

    Serial.print("Preview Ready! Use 'http://");
    Serial.print(WiFi.localIP());
    Serial.print("' to connect. Device name: ");
    Serial.println(g_config.device_name);
}

void loop() {
    delay(100);
}

// Push the config's camera defaults into the running sensor.
static void apply_camera_defaults_from_config() {
    sensor_t *s = esp_camera_sensor_get();
    if (!s) return;

    s->set_framesize(s,      (framesize_t)g_config.framesize);
    s->set_quality(s,        g_config.quality);
    s->set_brightness(s,     g_config.brightness);
    s->set_contrast(s,       g_config.contrast);
    s->set_saturation(s,     g_config.saturation);
    s->set_special_effect(s, g_config.special_effect);
    s->set_wb_mode(s,        g_config.wb_mode);
    s->set_whitebal(s,       g_config.awb);
    s->set_awb_gain(s,       g_config.awb_gain);
    s->set_exposure_ctrl(s,  g_config.aec);
    s->set_aec2(s,           g_config.aec2);
    s->set_ae_level(s,       g_config.ae_level);
    s->set_aec_value(s,      g_config.aec_value);
    s->set_gain_ctrl(s,      g_config.agc);
    s->set_agc_gain(s,       g_config.agc_gain);
    s->set_gainceiling(s,    (gainceiling_t)g_config.gainceiling);
    s->set_bpc(s,            g_config.bpc);
    s->set_wpc(s,            g_config.wpc);
    s->set_raw_gma(s,        g_config.raw_gma);
    s->set_lenc(s,           g_config.lenc);
    s->set_hmirror(s,        g_config.hmirror);
    s->set_vflip(s,          g_config.vflip);
    s->set_dcw(s,            g_config.dcw);

    if (g_config.led_intensity > 0) {
        enableLED();
        setLedValue(g_config.led_intensity);
    }
}

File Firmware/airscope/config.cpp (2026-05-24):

#include "config.h"
#include "FS.h"
#include "SD_MMC.h"
#include <ArduinoJson.h>   // install via Library Manager: "ArduinoJson"
#include <WiFi.h>

AirscopeConfig g_config;

static const char* CONFIG_PATH = "/config.json";

String config_default_device_name() {
    uint8_t mac[6];
    WiFi.macAddress(mac);
    char buf[12];
    snprintf(buf, sizeof(buf), "def-%02X%02X", mac[4], mac[5]);
    return String(buf);
}

void config_load_defaults() {
    // Hardcoded fallbacks. These are what runs if SD is missing or
    // config.json is unreadable. Default to the open institutional IoT
    // SSID so a freshly flashed board with no SD card still associates
    // on the lab network.
    //
    // Only seven fields are persisted to /config.json (see
    // config_load_from_sd / config_save_to_sd below): the network creds,
    // the device name, and the four most-tweaked camera knobs (quality,
    // gain, exposure, LED). Everything else here is hardcoded firmware
    // baseline that the host can still override at runtime via /control;
    // those tweaks just don't survive a reboot.
    g_config.wifi_ssid           = "servicenet";
    g_config.wifi_password       = "";
    g_config.device_name         = config_default_device_name();
    g_config.default_capture_time = 5;

    g_config.framesize        = 13;    // UXGA (1600x1200)
    g_config.quality          = 6;
    g_config.brightness       = 0;
    g_config.contrast         = 0;
    g_config.saturation       = 0;
    g_config.special_effect   = 2;     // grayscale
    g_config.wb_mode          = 0;
    g_config.awb              = 0;
    g_config.awb_gain         = 0;
    g_config.aec              = 0;
    g_config.aec2             = 0;
    g_config.ae_level         = 0;
    g_config.aec_value        = 1200;
    g_config.agc              = 0;
    g_config.agc_gain         = 1;
    g_config.gainceiling      = 2;
    g_config.bpc              = 1;
    g_config.wpc              = 1;
    g_config.raw_gma          = 0;
    g_config.lenc             = 0;
    g_config.hmirror          = 0;
    g_config.vflip            = 1;
    g_config.dcw              = 0;
    g_config.led_intensity    = 0;
}

bool config_load_from_sd() {
    if (!SD_MMC.exists(CONFIG_PATH)) {
        Serial.printf("[config] %s not present, using defaults\n", CONFIG_PATH);
        return false;
    }
    File f = SD_MMC.open(CONFIG_PATH, FILE_READ);
    if (!f) {
        Serial.printf("[config] failed to open %s\n", CONFIG_PATH);
        return false;
    }
    StaticJsonDocument<2048> doc;
    DeserializationError err = deserializeJson(doc, f);
    f.close();
    if (err) {
        Serial.printf("[config] parse error: %s, using defaults\n", err.c_str());
        return false;
    }

    bool got_any = false;
#define LOAD_STR(name) \
    if (doc.containsKey(#name)) { g_config.name = doc[#name].as<const char*>(); got_any = true; }
#define LOAD_INT(name) \
    if (doc.containsKey(#name)) { g_config.name = doc[#name].as<int>(); got_any = true; }

    // Only seven keys are recognized. Anything else in the file is ignored.
    LOAD_STR(wifi_ssid);
    LOAD_STR(wifi_password);
    LOAD_STR(device_name);
    LOAD_INT(quality);
    LOAD_INT(agc_gain);     // "gain" in user-facing docs
    LOAD_INT(aec_value);    // "exposure" in user-facing docs
    LOAD_INT(led_intensity);

#undef LOAD_STR
#undef LOAD_INT

    Serial.printf("[config] loaded from SD (ssid=%s, device=%s)\n",
                  g_config.wifi_ssid.c_str(), g_config.device_name.c_str());
    return got_any;
}

bool config_save_to_sd() {
    StaticJsonDocument<512> doc;
    // Only seven persisted keys. The rest live in firmware defaults.
    doc["wifi_ssid"]     = g_config.wifi_ssid;
    doc["wifi_password"] = g_config.wifi_password;
    doc["device_name"]   = g_config.device_name;
    doc["quality"]       = g_config.quality;
    doc["agc_gain"]      = g_config.agc_gain;       // "gain"
    doc["aec_value"]     = g_config.aec_value;      // "exposure"
    doc["led_intensity"] = g_config.led_intensity;

    File f = SD_MMC.open(CONFIG_PATH, FILE_WRITE);
    if (!f) {
        Serial.printf("[config] save: failed to open %s for write\n", CONFIG_PATH);
        return false;
    }
    if (serializeJsonPretty(doc, f) == 0) {
        Serial.println("[config] save: serializeJsonPretty wrote 0 bytes");
        f.close();
        return false;
    }
    f.close();
    Serial.println("[config] saved to SD");
    return true;
}

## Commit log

2025-09-25 Airscope design documents
    [AN2051.SLDASM, AR0130CS.SLDASM, Assem.SLDASM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]
2026-05-29 hardware: move electronics designs into Electronics
    [Burning-Bottom_Cu.gbr, Burning-Bottom_Mask.gbr, Burning-Bottom_Paste.gbr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]
2026-05-29 cad: reorganize mechanical and optical design files
    [100.STL, 150.STL, 200.STL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]

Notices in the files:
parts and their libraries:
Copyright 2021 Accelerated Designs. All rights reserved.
